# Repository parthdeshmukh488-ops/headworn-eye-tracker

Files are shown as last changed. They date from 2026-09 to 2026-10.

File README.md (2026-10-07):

# Head-worn eye tracker on a 3D-printed frame

A pair of printed glasses carrying an eye camera and a scene camera, tracking
the iris in **visible light** — no infrared emitter next to the eye — and
mapping gaze onto a screen using ArUco markers.

The frame is parametric OpenSCAD rather than a dropped STL, so the numbers that
decide whether it fits a given face and a given camera are editable and
readable.

**Status:** software only, so far. The frame has not been printed and no real
eye has been recorded yet; every number on this page comes from synthetic data.
The live tools for a real rig are in place (see *From images to gaze, live*).
Python 3.10+, numpy only for the core, OpenCV for everything camera-side.

```bash
pip install -e ".[dev,camera]"
pytest                             # 74 tests, no hardware
python examples/01_end_to_end.py   # the geometry, from pupil positions
python examples/02_image_pipeline.py   # the same chain, from images
python examples/make_figures.py    # redraws docs/figures/
```

---

## Why visible light, and what it costs

Almost every head-worn tracker uses IR illumination, and for a good reason:
under IR the pupil is by far the darkest thing in the image and the boundary is
trivially thresholdable. This rig puts no emitter next to the eye, which costs:

- **Pupil-iris contrast now depends on iris colour.** A dark brown iris gives a
  boundary a threshold can barely find; a blue one is easy. IR does not care.
- **Specular reflections land on the cornea** from whatever is in the room —
  several of them, in unknown places, rather than one known glint.
- **Eyelashes cross the pupil**, are dark, and survive thresholding.

The detection pipeline is built around those three in that order. The ellipse
fit is **robust rather than least-squares**, because least-squares is pulled
badly by exactly the contaminants that survive:

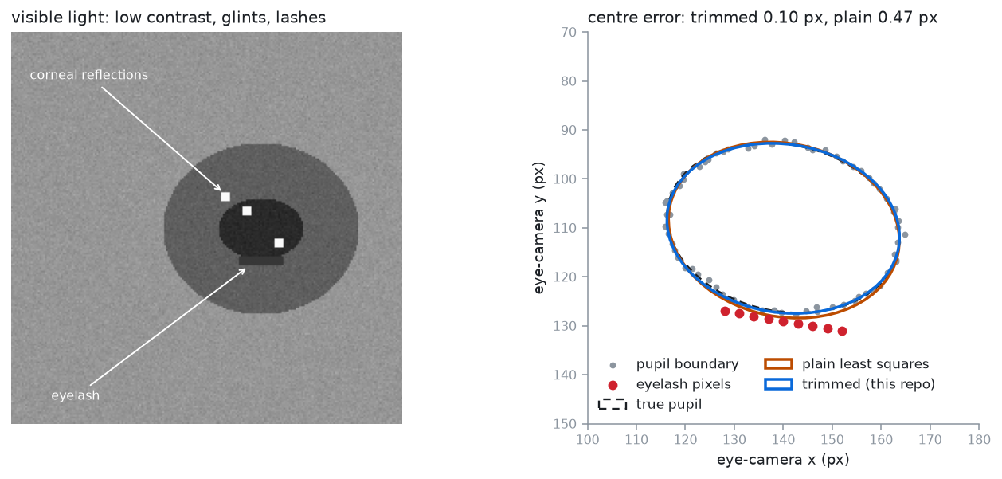
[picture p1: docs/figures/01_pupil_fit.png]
Trimmed fit against plain least squares


A handful of eyelash pixels drags the plain conic fit off centre. Trimming the
worst-fitting fraction and refitting costs three extra iterations and recovers
the centre to a tenth of a pixel.

---

## Two stages, kept separate

This is the design decision the whole thing rests on.

| | Eye → scene | Scene → screen |
|---|---|---|
| Kind | **fitted**, from calibration | **geometric**, exact |
| Model | degree-2 polynomial | homography |
| Depends on head pose | no | yes |
| Recomputed | once, at calibration | **every frame** |

A flat screen viewed by a pinhole camera is a plane-to-plane projective map, so
a homography is not an approximation here — it is the exact model. And because
head pose lives entirely in that stage, the fitted stage never has to account
for where the head is.

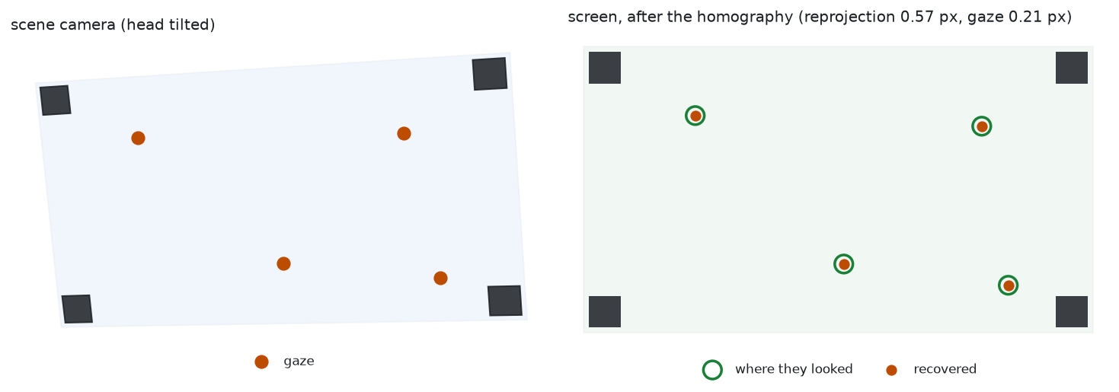
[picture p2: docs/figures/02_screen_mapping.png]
Scene camera to screen, through the homography


Caching the homography is the bug. The whole point of a head-worn rig is that
the head moves; a homography from one head pose is wrong for every other one.

---

## The over-determination problem

A homography has eight degrees of freedom, and each point correspondence
contributes two equations. So **four points — the four marker centres — fit
exactly, including nonsense ones.** The residual is zero whatever you feed it,
and it cannot tell you a marker was mislabelled or detected in the wrong place.

ArUco detectors return four corners per marker anyway, so this repo keeps all
of them. Four markers become sixteen points, thirty-two equations against eight
unknowns, and reprojection error finally carries information:

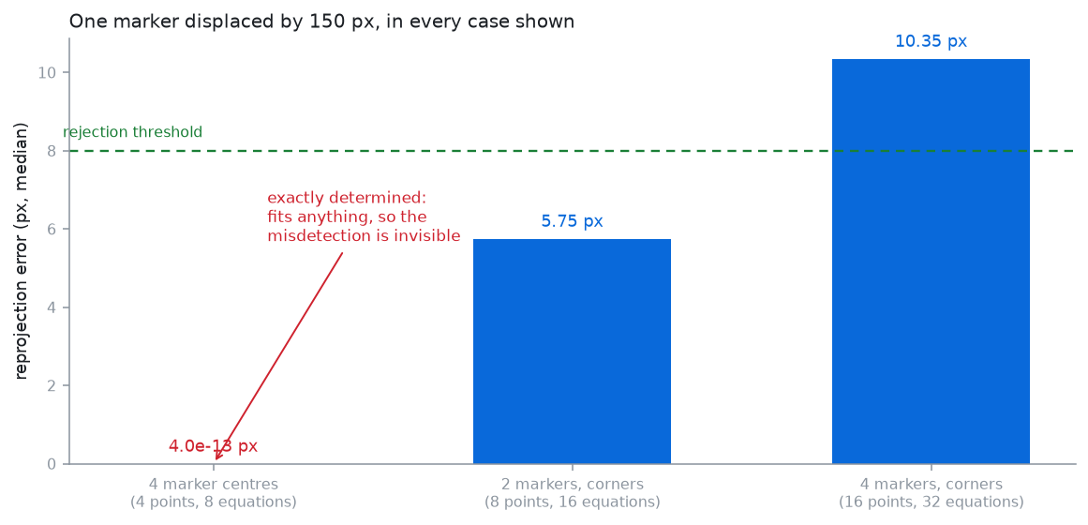
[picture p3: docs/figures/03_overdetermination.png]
Centres are blind, corners are not


There are tests for a displaced marker and for two swapped markers, and both
are caught. There is also a test asserting that four correspondences fit
anything exactly, so the reason for the design cannot quietly be forgotten.

Two markers is the working minimum — the wearer turning their head takes
markers out of frame constantly — and at two the system is already
over-determined, so the check still works.

---

## Numbers

`python examples/01_end_to_end.py`, synthetic wearer, head pose different on
every test frame:

```
Calibration: 12 points, 6 parameters
  in-sample residual        6.41 px   (0.17 deg)
  leave-one-out            13.48 px   (0.36 deg)
  overstatement          2.1x if in-sample is quoted

Test: 200 gaze points, head pose different on every frame
  frames rejected        0 (0.0%)
  accuracy, mean         2.86 deg
  accuracy, median       2.54 deg
  accuracy, p95          5.98 deg
```

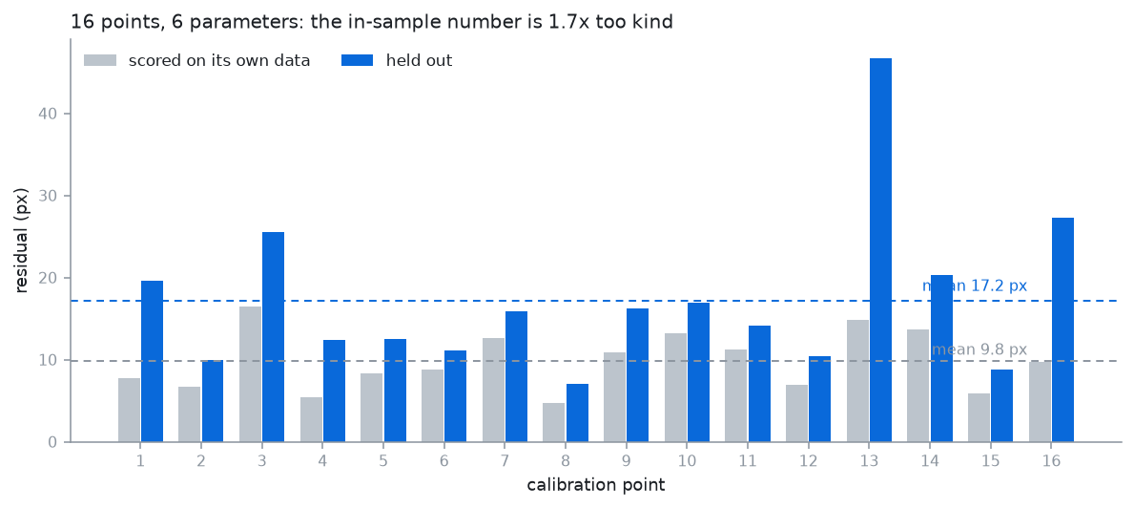
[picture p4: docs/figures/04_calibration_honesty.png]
In-sample against leave-one-out, per calibration point


Three things in that output worth reading carefully:

1. **The in-sample residual overstates by 2.1×.** Twelve calibration points
   against six parameters leaves half the degrees of freedom. At that ratio the
   in-sample number is not an accuracy estimate, and a repo that quoted 0.17°
   here would be claiming commercial-tracker performance from a printed frame.
2. **The test accuracy is worse again**, at 2.86°. The test points are spread
   across the whole screen, including outside the calibration grid, and the
   head poses are stronger. This is the number that describes the rig.
3. **The map was fitted once** and never refitted, across 200 different head
   poses, with nothing rejected. That is the two-stage separation working.

---

## From images to gaze, live

Example 01 starts from pupil *positions*. A real rig starts from *images*, so
`detect.py` turns an eye frame into a pupil and `aruco.py` turns a scene frame
into marker corners.

**Finding the pupil.** A single "darkest x %" threshold does not work: how much
of the frame the pupil covers depends on the rig, the person and the light. A
low threshold keeps only the pupil's dark core; the next one up already merges
lashes and iris. So the detector tries several dark fractions, fits an ellipse
to each plausible blob, keeps the darkest blob that fits and stands out from
its surround as a **seed**, then thresholds again **halfway between the seed's
grey level and its surround's**, which cuts at the pupil's actual edge. A blob
that is not clearly darker than the ring around it is never accepted, so a
blink or a blank frame is a dropout, not a guess.

`python examples/02_image_pipeline.py`, synthetic eyes with glints and lashes,
and a rendered marker screen seen through a tilted scene camera:

```
Pupil detection, 200 synthetic eyes per iris colour (glints and lashes on)
  dark brown  centre error median 0.22 px, p95 0.96 px, dropouts 0/200
  brown       centre error median 0.25 px, p95 1.17 px, dropouts 0/200
  light blue  centre error median 0.20 px, p95 0.92 px, dropouts 0/200

Full chain from images, head pose different on every frame
  calibration, leave-one-dot-out   2.1 scene px (max 4.3)
  validation accuracy              0.08 deg
  validation precision (RMS-S2S)   0.21 deg
  data loss                        0.0 %
```

These numbers say the code is right, not that a printed rig reaches 0.08°.
Synthetic eyes have clean edges and no lids; a real eye under room light will
be much worse, and only a recorded session can say by how much.

**The live tools** (`python -m headgaze ...`, eye and scene camera given by index
or as a recorded video):

| Command | What it does |
|---|---|
| `print-markers` | A 300 dpi page with the four markers at real size, to tape on the screen corners |
| `preview` | Fullscreen marker screen with both camera views: is the pupil found, are the markers seen? |
| `calibrate` | Nine dots; fits the eye-to-scene map, reports leave-one-dot-out error, saves `data/calibration.json` |
| `validate` | Nine *other* dots; accuracy, precision and data loss in degrees, saved to `results/` |
| `serve` | Streams gaze over UDP in the format of [gaze-robot-camera](https://github.com/parthdeshmukh488-ops/gaze-robot-camera-mujoco), so the headset can steer the robot camera |

The session protocol for a first real recording, including the slippage test, is
in [docs/SESSION_PROTOCOL.md](docs/SESSION_PROTOCOL.md).

---

## The frame

`hardware/frame.scad` — parametric, three printable parts.

```bash
openscad -o frame.stl hardware/frame.scad
openscad -o eye_arm.stl -D 'part="eye_arm"' hardware/frame.scad
```

The parameters that actually matter are pupillary distance (get it wrong and
the eye camera looks at a cheekbone), and the eye camera's drop, reach and
pitch. One eye camera, not two: gaze is conjugate for anything beyond arm's
length, so a second doubles the weight, cabling and synchronisation for very
little.

**Prefer PETG to PLA.** PETG tolerates heat better (a warm room, a sunny desk)
and creeps less under a constant load. That matters for the eye arm: if it
sags even slightly, gaze drifts slowly, which looks exactly like calibration
decay and is not. This is a design choice from material properties; the frame
has not yet been printed or worn.

---

## What this does not do

- **Parallax is not corrected.** The eye camera sees the eye, not what the eye
  is looking at, so the fitted map is exact only at the depth it was calibrated
  at. Calibrate at a 60 cm screen, look at something 3 m away, and there is a
  systematic offset. Fixing it needs a stereo scene camera or a depth estimate;
  this rig has neither.
- **Slippage is detected, not corrected.** `slippage_indicator` compares the
  recent pupil centroid against the calibration centroid, which catches a bulk
  shift of the glasses on the face. It cannot see frame rotation, and it will
  false-positive on someone who genuinely spent a minute looking at one corner.
  It is something to show the wearer, not to trigger anything automatic.
- **No blink detection beyond the confidence score.** A fit that looks like an
  eyelid edge scores low and is treated as a dropout; there is no dedicated
  blink classifier.
- **Detection is not benchmarked on real eye images yet.** The tests use
  synthetic eye images degraded in the three ways described above. That
  validates the pipeline, not its behaviour on real skin, lids and lashes.
- **Nothing has run on hardware yet.** The camera code is tested on replayed
  synthetic videos, not on two real USB cameras.
- **Monocular.** No vergence, so no depth of gaze.

---

## Layout

```
src/headgaze/
  pupil.py      visible-light pupil detection pieces and robust ellipse fitting
  screen.py     ArUco marker layout, homography, per-frame screen locator
  mapping.py    fitted eye-to-scene map, cross-validation, slippage, save/load
  metrics.py    accuracy, precision and data loss in degrees of visual angle
  stream.py     gaze over UDP, One Euro filter
  detect.py     eye image -> pupil (OpenCV)
  aruco.py      drawing and detecting the screen markers (OpenCV)
  session.py    one frame pair -> one gaze sample; calibration and validation
  live.py       two cameras and the fullscreen display (OpenCV)
  synthetic.py  synthetic eye images for tests and examples
  __main__.py   the live tools
hardware/
  frame.scad    parametric glasses frame, three printable parts
examples/
  01_end_to_end.py     the geometry numbers above
  02_image_pipeline.py the image-level numbers above
  make_figures.py      the figures above
docs/
  SESSION_PROTOCOL.md  parts list and the first real recording
  AUDIT.md             what was checked on 7 Oct 2026, and what changed
```

---

## Built with AI assistance

Large parts of this repository were written with AI coding tools (Claude). The
author reviewed it and can explain how each part works; see
[EXPLAIN.md](EXPLAIN.md) for the plain-English version.

---

## License

MIT — see [LICENSE](LICENSE).

Parth Deshmukh

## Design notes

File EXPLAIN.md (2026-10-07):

# How this project works, in plain English

Read this until you can tell it without looking.

## 1. What it is (say this first)

A pair of glasses with two small cameras: one looks at your eye, one looks forward
at what you see. From the eye camera the program finds your pupil; from the forward
camera it finds four printed markers on the corners of the screen. Together they tell
where on the screen you are looking, even while your head moves. It uses normal light
only, with no infrared lamp next to the eye.

**Honest status:** the software is written and tested on simulated images. The glasses
have not been built yet, so there are no measurements with a real eye.

## 2. How it works: five steps

1. **Find the pupil.** The eye camera image is searched for the darkest round blob.
   Bright reflections are painted dark first, specks from eyelashes are cleaned away,
   and an ellipse is fitted in a way that ignores the worst-fitting edge points.
2. **Pupil to forward-camera point.** A calibration (you look at 9 dots) teaches the
   program which pupil position means which point in the forward camera's picture.
   This never changes while the glasses sit still on your face.
3. **Find the screen.** The forward camera sees the four markers. From their corners the
   program computes, *in every single frame*, how the camera picture maps onto the screen
   (a *homography*: the exact mapping between two flat surfaces).
4. **Gaze on the screen.** Step 2 gives the point in the camera picture, step 3 maps it
   onto the screen.
5. **Send it on.** The gaze point goes over a local network message to the robot-camera
   demo, so the glasses can steer the robot instead of the webcam.

## 3. The ideas worth saying in an interview

- **Why no infrared?** Infrared makes the pupil easy to find, but putting a light source
  next to an eye needs a proper safety check. With normal light the pupil is harder to find:
  dark brown eyes give little contrast, room lights make reflections, and eyelashes are dark too.
- **Why two separate stages?** The pupil-to-camera relation only depends on how the glasses
  sit, so it is calibrated once. The camera-to-screen relation depends on where your head is,
  so it is recomputed every frame. Keeping them apart is what lets you move your head.
- **Why use all marker corners?** Four points always fit a homography exactly, even wrong ones,
  so you cannot tell when a marker was misread. Sixteen corners give a check.
- **How it fails differently from the webcam tracker.** The webcam tracker gets worse when you
  move your head. The glasses don't care about head movement, but they get worse when they
  *slip* on your nose, because the calibration assumed the camera stays where it was.
- **Why validate on new dots?** Accuracy measured on the calibration dots looks far better
  than it really is; only new points give an honest number.

## 4. Files

| File | What it is for |
| --- | --- |
| `src/headgaze/detect.py` | Eye image to pupil |
| `src/headgaze/pupil.py` | The pieces: reflection removal, threshold, robust ellipse fit, confidence |
| `src/headgaze/mapping.py` | The calibrated pupil-to-camera map, its honest error estimate, slippage check |
| `src/headgaze/aruco.py` | Drawing and finding the screen markers |
| `src/headgaze/screen.py` | Camera picture to screen (the homography), recomputed every frame |
| `src/headgaze/session.py` | One pair of frames to one gaze point; calibration and validation |
| `src/headgaze/metrics.py` | Errors in degrees of visual angle |
| `src/headgaze/stream.py` | Sends gaze to the robot demo; smoothing filter |
| `src/headgaze/live.py`, `__main__.py` | The cameras, the fullscreen screen, the commands |
| `hardware/frame.scad` | The glasses frame as an editable 3D design |
| `docs/SESSION_PROTOCOL.md` | What to buy and how the first real recording works |

## 5. Results

**Simulated only** (say "simulated" every time): on synthetic eye images the pupil centre is
found to within about a quarter of a pixel, and the whole chain reaches about 0.1° on the screen
with the head moving. That shows the code is right. A real eye in room light will be much worse;
the real number comes from the first session: [TBD].

## 6. Likely questions, honest answers

1. **"Have you built it?"** "Not yet. The software is done and tested on simulated images; the
   cameras and frame are the next step, and I've written the recording plan."
2. **"Why not infrared like everyone else?"** See section 3: safety, at the price of contrast.
3. **"What's the biggest problem with head-worn trackers?"** Slippage of the glasses, and parallax:
   calibrated at the screen distance, it is off when you look much nearer or further.
4. **"How would you test it?"** Accuracy on new dots with the head still, with the head moving,
   and after taking the glasses off and on five times; compared with the webcam tracker in the same light.
5. **"Did you write this yourself?"** "I built it with a lot of help from AI coding tools and went
   through how each part works."

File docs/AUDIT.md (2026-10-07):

# Audit, 7 Oct 2026

What was checked before extending the repository, and what changed.

## Reproduced

- All 58 existing tests pass on Windows 10, Python 3.13.
- `examples/01_end_to_end.py` prints exactly the numbers quoted in the README.
- `ruff check` and `ruff format --check` pass.

## Gaps found

1. **No image-to-pupil step.** `pupil.py` had the pieces (glint suppression,
   threshold estimate, robust ellipse fit, confidence), but nothing turned an eye
   image into a `PupilEstimate`. The README's "detection pipeline" existed only for
   synthetic point sets. Added `detect.py`.
2. **No camera, ArUco or live code.** Nothing read cameras, detected markers in an
   image or ran a calibration with a person. Added `aruco.py`, `live.py`,
   `session.py` and the `python -m headgaze` tools.
3. **No connection to the robot-camera project.** Added `stream.py`, which sends the
   same UDP messages as `gaze-robot-camera`.
4. **Wording that read as hardware experience.** The status line ("personal project,
   rebuilt and published") and the PETG paragraph read as if the frame had been
   printed and worn. Neither has happened yet; both now say so.

## Notes

- Example 01 converts calibration residuals from scene-camera pixels to degrees with
  the screen's pixel size. That is acceptable there because its simulated scene
  camera sees the screen at close to 1:1 scale; it would not be with a real camera.
  `session.py` reports calibration error in scene pixels and leaves degrees to
  `validate`, which measures them on the screen.
- The first version of `detect.py` used one fixed dark fraction and, on synthetic
  eyes, often fitted the iris instead of the pupil (right centre, because the two
  are concentric, but the wrong size). The tests caught it; the seed-then-midpoint
  threshold replaced it.

## Added tests

- `test_detect.py`: pupil centre under glints and lashes for three iris colours; no
  pupil reported for a blank frame or a closed eye.
- `test_aruco.py`: markers drawn where the layout says; the screen located through a
  tilted, noisy scene camera to within 3 screen pixels.
- `test_session.py`: calibration and validation from synthetic images with the head
  moving on every frame.
- `test_serve_replay.py`: `serve` on replayed videos sends correct UDP messages.
- `test_stream_metrics_io.py`: message format, filter, visual-angle maths, save/load.

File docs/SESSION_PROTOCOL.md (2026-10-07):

# First real session: parts, build, recording

Nothing in this repository has run on real hardware yet. This page is the plan
for the first session; fill in the results table at the end with what really
happens, including what fails.

## Parts (about 30–50 euro)

| Part | What to look for |
| --- | --- |
| Eye camera | USB endoscope camera with a 5.5–8 mm head that focuses at 2–5 cm; its LEDs must dim or switch off |
| Scene camera | Small USB webcam, 640×480 MJPG at 30 fps, field of view around 70° |
| Frame | `hardware/frame.scad` printed in PETG, or cheap safety glasses with printed clips |
| Markers | `python -m headgaze print-markers`, printed at 100 % on plain paper, four pieces of tape |
| Small parts | Zip ties, a USB extension cable, a kitchen scale for the weight |

## Safety

- **No infrared light near the eye.** This rig works in visible light on purpose.
- Turn the endoscope camera's LEDs off, or to the lowest setting if they cannot be switched off.
- Stop if the eye feels uncomfortable or dry.

## Set-up (about 20 minutes)

1. Print the markers and measure the black squares. If the printer scaled them, pass the
   measured size to `serve` with `--marker-mm`. Tape them upright
   on the screen corners: the black square's outer corner exactly on the corner of the
   visible screen (0 top-left, 1 top-right, 2 bottom-right, 3 bottom-left).
2. Light from the front, no window behind the screen.
3. `python -m headgaze preview --eye 1 --scene 2`. Swap the indices if the views are
   swapped. Adjust the eye camera until the whole eye is in view with the pupil near the
   centre, and the status line shows the pupil found and 4/4 markers.

## Recording (about 30 minutes)

Use your measured eye-to-screen distance and screen width in every command
(`--distance-cm`, `--screen-width-cm`).

1. `python -m headgaze calibrate`: keep the head still, follow the dots with the eyes.
2. `python -m headgaze validate --note "head still"`.
3. `python -m headgaze validate --note "head moving"`: follow the dots while moving the head
   gently.
4. **Slippage:** take the glasses off and put them back on, then
   `python -m headgaze validate --note "re-seated 1"`, without recalibrating. Repeat five times.
5. **Comparison:** in the same light, run the webcam tracker's validation from
   `gaze-robot-camera` (its RUN_ME_FIRST.md, steps 2–3).
6. Weigh the headset and take a photo of it.
7. **Robot demo:** `python -m headgaze serve --markers paper` here, and
   `python -m app free --gaze udp --fullscreen` in `gaze-robot-camera`.

## Results (fill in only with recorded numbers)

| Condition | Head-worn accuracy (°) | Webcam accuracy (°) | Head-worn data loss (%) |
| --- | --- | --- | --- |
| Head still | [TBD] | [TBD] | [TBD] |
| Head moving | [TBD] | [TBD] | [TBD] |
| After re-seating (mean of 5) | [TBD] | not applicable | [TBD] |

Headset weight: [TBD] g. What failed first, and why: [TBD].

The expected story, to check rather than assume: the webcam tracker gets worse when
the head moves; the head-worn one should not, but it gets worse after re-seating,
because its calibration assumes the camera sits where it sat during calibration.

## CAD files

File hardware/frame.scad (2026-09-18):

// Head-worn eye tracker: parametric glasses frame
//
// Holds one eye camera looking back at the right eye and one scene camera
// looking forward. Written parametrically rather than shipped as an STL so
// that the dimensions that matter can be changed for a different face or a
// different camera without redoing the model.
//
//   openscad -o frame.stl frame.scad
//   openscad -o frame_eye_arm.stl -D part=\"eye_arm\" frame.scad
//
// Print notes are at the bottom of this file.

/* [Which part] */
// "all" previews the assembly; the others are the printable parts.
part = "all";  // [all, front, eye_arm, temple]

/* [Face fit] */
// Pupillary distance. The single most important number here: get it wrong and
// the eye camera looks at a cheekbone.
pupillary_distance = 63;
// Width across the temples, at the hinge.
head_width = 145;
// Bridge width, between the lens openings.
bridge_width = 18;
// How far the front sits from the eyes.
vertex_distance = 14;

/* [Eye camera] */
// A bare USB camera module, without its housing.
eye_cam_w = 8.5;
eye_cam_h = 8.5;
eye_cam_d = 5.0;
// How far below the eye the camera sits, and how far forward.
eye_cam_drop = 22;
eye_cam_forward = 26;
// Angle up towards the eye. 30-35 degrees keeps the iris in frame across the
// full range of gaze without the arm entering the wearer's field of view.
eye_cam_pitch = 32;

/* [Scene camera] */
scene_cam_w = 12;
scene_cam_h = 12;
scene_cam_d = 6;
// Sitting on the bridge keeps it near the cyclopean eye, which minimises the
// parallax between what it sees and what the wearer sees. It cannot remove it.
scene_cam_rise = 6;

/* [Structure] */
front_thickness = 4;
front_height = 34;
lens_opening_w = 46;
lens_opening_h = 28;
temple_length = 130;
temple_thickness = 4;
arm_thickness = 3.5;
arm_width = 7;

/* [Print] */
// Clearance on every camera pocket. 0.3 mm suits a well-tuned FDM printer;
// raise it to 0.4 if parts need forcing, because forcing a camera into a
// pocket is how the lens gets scratched.
fit_clearance = 0.3;

$fn = 48;

// ---------------------------------------------------------------- front

module lens_opening() {
    // Rounded rectangle, built from a hull of four cylinders. Sharp internal
    // corners concentrate stress and this part gets flexed every time the
    // glasses are put on.
    r = 6;
    hull() {
        for (dx = [-1, 1], dy = [-1, 1])
            translate([dx * (lens_opening_w / 2 - r), dy * (lens_opening_h / 2 - r), 0])
                cylinder(r = r, h = front_thickness * 3, center = true);
    }
}

module front() {
    half = pupillary_distance / 2;
    width = pupillary_distance + lens_opening_w + 14;

    difference() {
        // Body
        hull() {
            for (dx = [-1, 1])
                translate([dx * (width / 2 - 8), 0, 0])
                    cylinder(r = 8, h = front_thickness, center = true);
        }

        // The two lens openings
        for (dx = [-1, 1])
            translate([dx * half, 0, 0]) lens_opening();

        // Bridge relief, so the frame does not sit on the nose ridge
        translate([0, -front_height / 2, 0])
            scale([bridge_width / 2, 8, 1])
                cylinder(r = 1, h = front_thickness * 3, center = true);

        // Scene camera pocket, on the bridge
        translate([0, front_height / 2 - scene_cam_h / 2 + scene_cam_rise, 0])
            cube([scene_cam_w + fit_clearance,
                  scene_cam_h + fit_clearance,
                  front_thickness * 3], center = true);
    }
}

// ---------------------------------------------------------------- eye arm

module eye_camera_pocket() {
    cube([eye_cam_w + fit_clearance,
          eye_cam_h + fit_clearance,
          eye_cam_d + fit_clearance], center = true);
}

module eye_arm() {
    // An L: down from the frame, then forward and up under the eye.
    difference() {
        union() {
            // Vertical leg
            translate([0, -eye_cam_drop / 2, 0])
                cube([arm_width, eye_cam_drop, arm_thickness], center = true);

            // Forward leg, pitched up towards the eye
            translate([0, -eye_cam_drop, 0])
                rotate([eye_cam_pitch, 0, 0])
                    translate([0, 0, eye_cam_forward / 2])
                        cube([arm_width, arm_thickness, eye_cam_forward], center = true);

            // Camera boss at the end
            translate([0, -eye_cam_drop, 0])
                rotate([eye_cam_pitch, 0, 0])
                    translate([0, 0, eye_cam_forward])
                        cube([eye_cam_w + 4, eye_cam_h + 4, eye_cam_d + 3], center = true);
        }

        // Camera pocket, opening forwards
        translate([0, -eye_cam_drop, 0])
            rotate([eye_cam_pitch, 0, 0])
                translate([0, 0, eye_cam_forward])
                    eye_camera_pocket();

        // Cable channel down the back of the arm
        translate([0, -eye_cam_drop / 2, -arm_thickness / 2])
            cube([2.5, eye_cam_drop + 2, 1.5], center = true);
    }
}

// ---------------------------------------------------------------- temple

module temple() {
    difference() {
        union() {
            cube([temple_thickness, temple_length, 9], center = true);

            // Ear hook
            translate([0, temple_length / 2, 0])
                rotate([0, 90, 0])
                    rotate_extrude(angle = 70, $fn = 64)
                        translate([16, 0, 0])
                            square([temple_thickness, 9], center = true);
        }

        // Hinge pin hole
        translate([0, -temple_length / 2 + 6, 0])
            rotate([0, 90, 0])
                cylinder(r = 1.2, h = temple_thickness * 3, center = true);
    }
}

// ---------------------------------------------------------------- assembly

module assembly() {
    color("LightSteelBlue") front();

    // Eye arm on the right eye only. One eye is enough: gaze is conjugate for
    // anything beyond arm's length, and a second eye camera doubles the
    // weight, the cabling and the synchronisation problem for very little.
    translate([pupillary_distance / 2, -front_height / 2 + 4, vertex_distance / 2])
        color("Tomato") eye_arm();

    for (dx = [-1, 1])
        translate([dx * head_width / 2, front_height / 2 - temple_length / 2, 0])
            color("Gainsboro") temple();
}

if (part == "all") assembly();
else if (part == "front") front();
else if (part == "eye_arm") eye_arm();
else if (part == "temple") temple();

// ---------------------------------------------------------------- printing
//
// PETG rather than PLA. The frame sits on a face for an hour at a time and PLA
// softens enough at skin temperature over that period to let the eye arm
// droop, which shows up as a slow drift in gaze that looks exactly like
// calibration decay and is not.
//
// Front:    flat on the bed, no supports.
// Eye arm:  on its side, supports on. This part carries the camera and any
//           layer delamination in it becomes gaze error, so 4 perimeters.
// Temple:   flat, no supports; the ear hook bridges fine at this radius.
//
// After printing, check the eye arm does not enter the wearer's field of view
// when they look down. If it does, reduce eye_cam_pitch before reducing
// eye_cam_forward -- moving the camera closer costs more accuracy than
// flattening its angle.

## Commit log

2026-09-18 Package skeleton
    Core depends on numpy alone; OpenCV is an extra for the capture path only,
    which is what lets the test suite run with no cameras attached.
2026-09-18 Fitted eye-to-scene map, cross-validation and a slippage indicator
    Kept separate from the screen homography on purpose: only the homography
    depends on head pose, and it is resolved every frame, so the fitted stage
    never has to account for where the head is.
2026-09-18 Parametric glasses frame in OpenSCAD
    Three printable parts. PETG rather than PLA: PLA softens at skin temperature
    over an hour and lets the eye arm droop, which reads as gaze drift that looks
    exactly like calibration decay and is not.
    [frame.scad]
2026-09-18 End-to-end example and CI
    The example moves the head on every one of 200 test frames without refitting
    the eye-to-scene map, which is the two-stage separation doing its job.
2026-09-18 README: the visible-light trade-off, the two stages, and the measured numbers
2026-09-19 Correct the over-determination arithmetic in the locator docstring
    It claimed two markers give 'eight correspondences against eight unknowns --
    still an exact fit, so the residual is uninformative'. Wrong: each point
    correspondence contributes two equations, so two markers are 8 points and 16
    equations against 8 unknowns, already over-determined.
    The exactly-determined case is 4 points -- one marker's corners, or the four
    marker centres -- which is what ScreenMarkers refuses to construct. The code
    was right; the stated reason was not.
    Found by plotting it: a displaced marker showed up at two markers, which the
    docstring said was impossible.
2026-09-19 Figures: pupil fit, screen mapping, over-determination, calibration honesty
    The over-determination figure now compares marker centres against marker
    corners, which is the actual design decision, instead of comparing marker
    counts -- all of which are over-determined and none of which showed the
    blindness the design exists to avoid.
    Centres miss a 150 px misdetection by 4e-13 px. Corners catch it.
2026-10-07 From images to gaze: pupil detection, ArUco, live tools, robot-camera stream
    - detect.py: eye image to pupil. Several dark thresholds give candidate blobs;
    the darkest believable one seeds a second threshold halfway between its level
    and its surround's, which cuts at the pupil's edge. Blank frames and closed
    eyes are dropouts.
    - aruco.py: render the marker screen, detect markers in the scene camera.
    - session.py, live.py, __main__.py: preview, calibrate, validate, serve and
    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
